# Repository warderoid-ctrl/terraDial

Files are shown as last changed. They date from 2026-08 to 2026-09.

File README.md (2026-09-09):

# terraDial

Standalone control panel for the **terraPen** pen plotter, running on an
Elecrow CrowPanel 1.28" round display — a 240×240 touchscreen with a rotary
knob. It talks to [FluidNC](http://wiki.fluidnc.com/) over a WebSocket, so
the plotter can be driven from the bench without a laptop or phone.

Parent project: [terraForge](https://github.com/theworkisthework/terraForge)
(the desktop app this panel descends from — and the source of its colour
palette). Sibling: terraPixel (the rail lighting controller this panel can
also drive).

## What it does

- **Jog** X/Y/Z by knob, with selectable step sizes (0.1 / 1 / 10 / 100mm on
  X and Y; Z is capped at 1mm, being only a pen lift) and a per-axis *Set zero*
- **Run G-code** straight off the plotter's SD card, with live progress,
  elapsed time and an estimate of the time remaining — including for jobs
  started from terraForge or the web UI rather than the panel
- **Pen up/down**, **homing** (with a clear-the-bed confirmation), **E-Stop**
  and **alarm clear**, the last showing FluidNC's own reason for the alarm
- **Park for photo** — one dial item that lifts the pen, homes, then runs the
  gantry out to the far end of Y so the finished plot can be photographed
  unobstructed. Sequenced against the status stream rather than fired blind,
  since G-code sent mid-homing is rejected
- **Rail lighting** control via terraPixel — brightness, film mode, comet width
- **On-device Wi-Fi setup**: scan for networks, pick one, type the password
- **Machine status** shown on the panel's 5-LED ring, readable across the room
  — a jog chases a pixel the way you turned the knob, a plot breathes the
  whole ring slowly, and both dim with the screen when the panel sleeps
- **Sleep mode** so the panel isn't glowing at you through a multi-hour plot,
  with the terraPen mark shown while idle beforehand
- **About screen** carrying the project identity and QR links to the site,
  source and Discord — a 240px dial is no place to read a URL

## Screens

> These are **vector illustrations, not photographs.** They're generated by
> [`tools/gen_screens.py`](tools/gen_screens.py) from the real layout values —
> palette hex, ring radii, arc angles, hub and font sizes — so proportions and
> colours match the firmware, but icons are simplified stand-ins for LVGL's
> symbol font and the panel's actual anti-aliasing isn't reproduced.

| | | |
|:--:|:--:|:--:|
| <br>**Home** — 8 destinations, E‑Stop always red | <br>**Jobs** — SD files on an open arc | <br>**Jog** — axis, position, per‑axis zero |
| <br>**Job progress** — elapsed, and time left | <br>**Pen** — up / down | <br>**Home XY** — clear‑the‑bed gate |
| <br>**Lights** — terraPixel rail control | <br>**Settings** — four categories | <br>**Display** — brightness, sleep |
| <br>**Radial keyboard** — knob‑first text entry | <br>**E‑Stop** — feed hold + soft reset | <br>**Alarm clear** — appears on alarm |
| <br>**About** — identity, QR links, diagnostics | <br>**Idle** — the mark, before sleep | |

## Hardware

| | |
|---|---|
| Board | Elecrow CrowPanel 1.28" Rotary (ESP32-S3R8, 16MB flash, 8MB PSRAM) |
| Display | GC9A01 240×240 round IPS, SPI |
| Touch | CST816D capacitive, I²C |
| Input | EC11-style rotary encoder with push switch |
| LEDs | 5× WS2812 ring around the bezel |

Pin assignments are in [`include/pins.h`](include/pins.h), confirmed against
Elecrow's factory example for this exact board rather than guessed.

### Power

It's a **USB-powered device** — a single USB-C lead carries both power and,
when you want it, the serial console and firmware flashing. There's no barrel
jack and no separate supply to find.

That also means it runs happily off a **USB battery pack**, which is handy for
a plotter that isn't parked next to a socket, or for filming without a cable
in shot. Two things worth knowing if you do:

- Many power banks cut out when they stop seeing meaningful current draw.
  This panel is a modest load to begin with, and screen sleep drops it further
  by switching the backlight off entirely — so a bank with an aggressive
  auto-shutoff may power down mid-plot. Banks with a "low-current" or
  "trickle" mode avoid this; otherwise turn sleep off (Settings → Display)
  when running from one.
- The bezel LED ring draws on the same supply, so a high ring brightness
  costs battery life directly. It's on the Lights screen if you want it down.

Enclosure files (`dial case.stl`, `frame mount.stl`, `backplate.dxf`) are in
the repo root.

## Installing and updating

Neither of these needs a toolchain, a checkout, or anything installed on the
computer. The Building section below is for changing the firmware, not for
running it.

### First install — the web installer

<https://warderoid-ctrl.github.io/terraDial/>

Plug the panel into a computer with a USB-C **data** cable, open that page in
Chrome or Edge on the desktop, and click *Connect and install*. It talks to the
panel over Web Serial and writes the whole chip — bootloader, partition table
and app — so it also works on a board that has never been flashed, and on one
that has been flashed with something broken.

Safari, Firefox and every mobile browser lack Web Serial, so the page tells
them so rather than failing halfway.

Released builds ship with **no Wi-Fi credentials baked in** — the first boot
comes up unconnected, and you pick a network on the panel (Settings → Wi-Fi →
scan). That's the flow a stranger's board has to use anyway, so it's the one
that gets tested.

### After that — over Wi-Fi, from the panel

**Settings → About → Check for updates.**

The panel asks GitHub for the latest release, compares it against the version
it's running, and offers to install it. It downloads into the spare app slot
and reboots into it, so a failed or interrupted download leaves the working
firmware exactly where it was — there's no window where the panel is holding
half a firmware.

Two deliberate limits:

- **It refuses while the machine is busy.** The download blocks the same task
  that pumps FluidNC's WebSocket, for a minute or more, and the reboot at the
  end drops the connection outright. Mid-plot is the worst possible moment for
  both, so it says "Machine busy" and does nothing.
- **A dev build is always offered the release.** A build from a working copy
  carries the version `dev`, which has no place in the ordering — see
  `include/version.h`. If you're testing local firmware, don't press the button.

The About card shows the running version at the top, which is the thing worth
quoting in a bug report.

### Cutting a release

Tag it and push the tag; [`.github/workflows/release.yml`](.github/workflows/release.yml)
does the rest.

```bash
git tag v0.1.0
git push origin v0.1.0
```

That builds the firmware with the tag stamped in, attaches two images to the
GitHub Release, and redeploys the installer page:

| Asset | What it is |
|---|---|
| `terradial-ota.bin` | The app image. What the panel downloads for itself — the name is fixed, and `OTA_ASSET_NAME` in [`src/net/ota_updater.h`](src/net/ota_updater.h) has to keep matching it |
| `terradial-factory.bin` | Bootloader + partitions + app, merged for flashing at `0x0`. What the web installer writes |

Publishing the installer page is a second workflow,
[`pages.yml`](.github/workflows/pages.yml), which the first triggers on
success. That split isn't tidiness: the `github-pages` environment only
accepts deployments from the default branch, and a release workflow runs from
a tag — v0.1.0 failed exactly that way. A `workflow_run` trigger is evaluated
in the default branch's context whatever ref set it off, so it passes the rule
without anyone having to loosen a protection setting that lives nowhere in the
repo.

It downloads the factory image from the release it just made and serves it
from the Pages origin rather than linking to github.com — Web Serial fetches
the image with JS, and a cross-origin fetch the browser declines fails
quietly, which is a miserable thing to debug from a report that only says
"the button doesn't work".

**One-time repo setup:** Settings → Pages → Source must be set to *GitHub
Actions*, or the workflow builds everything and has nowhere to publish it.

### Test builds nobody else gets

A tag with a hyphen in it — `v0.2.0-rc1` — publishes as a GitHub
*prerelease*. It gets a release page and downloadable binaries like any
other, but no panel is offered it and the installer page ignores it: both
ask for `releases/latest`, and that endpoint skips prereleases.

That's also the only safe way to use a suffix. `versionRank()` in the
updater stops at the first non-digit, so `0.2.0-rc1` ranks *identically* to
`0.2.0` — two different builds it cannot tell apart. Keeping suffixed tags
out of `latest` means it never has to.

### Versions can only go forwards

The updater offers a release only when it ranks strictly higher than the
running build, and there is no downgrade path in the UI. So a bad release is
retired by tagging a **higher** number — never by deleting the release,
moving the tag, or re-uploading under the same one. None of those reach a
panel that has already updated.

## Building

Built with [PlatformIO](https://platformio.org/).

```bash
# 1. Wi-Fi credentials and hostnames -- secrets.h is gitignored
cp include/secrets.h.example include/secrets.h
$EDITOR include/secrets.h

# 2. Build and flash
pio run -t upload

# 3. Watch the logs
pio device monitor
```

Only the SSID and password are compile-time *defaults*: they're seeded into
NVS on first boot, after which the Settings screen can change networks
on-device without a reflash.

A local build reports its version as `dev` unless HEAD is exactly on a tag —
[`tools/version.py`](tools/version.py) only treats an exact tag as a release,
because a commit that merely descends from `v0.2.0` is newer than `v0.2.0`, and
stamping it as that version would have the updater cheerfully offer to
downgrade it.

## Using it

The knob is the primary input; touch works everywhere too.

| Gesture | Does |
|---|---|
| Rotate | Move through a ring / jog the selected axis / scroll a settings panel |
| Click | Open the highlighted item, or confirm |
| Long press | Back (out of a category first, then out of the screen) |
| Tap the centre hub | The running job, the active alarm, or E-Stop if the machine is moving — otherwise whatever the hub is naming |
| Double click | Run/delete prompt (Jobs screen only) |

**Home** is a radial dial of eight destinations, ordered the way a session
actually runs rather than by category — Home XY, Jog, Pen, Jobs, Photo,
E-Stop, Lights, Settings. The ring rests on the first of them, so the first
thing under the selection when the panel wakes is the first thing you do.
**Jobs** and **Settings** use the same ring on an open arc, which keeps the
bottom of the face clear of the back button.

Job Progress and Alarm Clear appear on their own when a job starts or an
alarm trips, and have no dial item of their own. The way back to them is the
hub: it already reports the machine state, so while that state has a screen,
tapping it opens that screen rather than the selected ring item.

That's what buys the spacing. The ring is a full circle, so every item costs
the others angle — eight sit 45° apart where ten sat 36°. E-Stop is a chip
you have to land on while something is going wrong, so it gets the room; it
also stays red at every position rather than only when selected.

Getting to E-Stop matters most where the machine is already moving under
your hand, which is not during a job — Job Progress carries its own stop
button. It's **jogging** and **homing**. So the Jog and Park screens carry a
small red stop pip beside their back button, and on the dial, tapping the
hub while the machine is homing or travelling opens E-Stop. Both open the
E-Stop screen rather than stopping outright: a stray tap near the bottom
bezel shouldn't soft-reset a machine mid-plot.

E-Stop fires on **press**, not on release, and says what it did. An
emergency jab that lands and slides off is exactly the gesture a normal
button is designed to discard, and the panel can't tell you the machine
stopped — only whether there was a connection to send the stop down. So it
answers "STOPPED" or "NOT SENT", the second meaning go and stop it by hand.

## Layout

```
.github/         release build, and the installer-page deploy that follows it
docs/screens/    README illustrations (generated)
include/         pins, palette, LVGL config, shared enums
lib/CST816D/     vendor touch driver
src/
  config/        NVS-backed settings
  display/       all UI screens and shared widgets
  input/         encoder driver
  led/           WS2812 status ring
  net/           FluidNC WebSocket client, terraPixel HTTP client, Wi-Fi
tools/           icon, logo and screen-illustration generation
web/             the browser-based firmware installer (published to Pages)
design_handoff_radial_dial_ui/   the original design brief (historical)
```

Some notes worth knowing before changing things:

- **Networking runs on core 0**, in its own task (see `networkTask` in
  `main.cpp`). mDNS lookups, WebSocket reads and HTTP calls all block for
  seconds at a time; running them in `loop()` stalls rendering and touch.
  Commands travel UI→network through a queue, and **nothing outside that task
  may touch LVGL** — LVGL is single-threaded and lives on core 1.
- **It's a round screen.** Anything more than ~120px from centre (120,120) is
  behind the bezel and physically unreachable, corners included. Several bugs
  have come from laying out against the 240×240 square instead of the circle.
- **Avoid `transform_zoom` / `lv_img_set_zoom` on anything whose parent has
  opacity < 255.** That combination pushes LVGL down an offscreen-layer path
  that is unreliable on this board — it has twice caused elements to render
  blank or vanish. Change real sizes instead.
- Colours come from [`include/palette.h`](include/palette.h), ported from
  terraForge's dark theme. Use the tokens, not literal hex.
- **The dial's order lives in three places** and they must agree:
  `DIAL_ITEMS` in `ui_dial.cpp`, the positional `switch` in `ui_nav.cpp`'s
  `onDialOpen()`, and the `screen_home()` item list in `tools/gen_screens.py`.
  Reordering one alone doesn't fail to build — it just quietly sends every
  item to the wrong screen.
- **Pace what you send FluidNC.** Commands are queued and the whole queue is
  drained in one pass, so two lines enqueued together hit the wire
  microseconds apart. `$X` immediately followed by `$H` used to alarm the
  machine on any home after the first; `home()` now unlocks only when there's
  actually an alarm and holds the `$H` until that has landed. For the same
  reason jogging is refused mid-homing — the jog-cancel realtime byte would
  stop the cycle, and FluidNC alarms on a homing cycle that didn't finish.
- Project links live in [`include/branding.h`](include/branding.h). The
  Discord URL is deliberately empty until there's a real invite — an entry
  with no URL is skipped rather than rendered as a QR that goes nowhere.
  `githubOwner()`/`githubRepo()` there are also what the updater queries, so
  a repo rename means editing them. The old **terraTouch** name still
  resolves, but only as a 301, and GitHub's API answers a redirect with a
  note about the move rather than the release — which is why the updater
  follows redirects, so a rename can't quietly kill the update path on
  panels already in the field.
- **`default_16MB.csv` is load-bearing.** The two app slots are what the OTA
  updater flashes into. A single-app partition table builds and runs perfectly
  and then fails every update at the point of no return.

## Licence

MIT — see [LICENSE](LICENSE). Same licence as its parent project
[terraForge](https://github.com/theworkisthework/terraForge).

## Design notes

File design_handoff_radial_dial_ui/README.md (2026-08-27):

# Handoff: TerraPen Dial Controller UI (historical)

> **Status: superseded. The firmware is the source of truth, not this file.**
>
> This is the design brief the panel was originally built from, kept for
> provenance — it's why the UI looks the way it does, and the palette,
> typography and icon-set sections below are still accurate and still worth
> reading before adding a screen.
>
> Everything describing *behaviour* has been overtaken by the shipped
> firmware. Where the two disagree, the firmware wins. The known divergences,
> as of the rename to terraDial:
>
> - **Home is a ring of nine, not eight**, and in a different order: Home XY,
>   Jog, Pen, Jobs, Progress, E-Stop, Alarm, Lights, Settings. `DIAL_ITEMS` in
>   `src/display/ui_dial.cpp` is authoritative.
> - **Job Progress is a dial destination**, not only an automatic screen.
> - **Jobs and Settings are rings on an open arc**, not carousels.
> - **There is no separate physical touch button** on this hardware. Back is a
>   knob long-press; E-Stop is a dial item, not a double-press gesture.
> - **Homing does not unconditionally send `$X`.** It unlocks only when the
>   machine is actually alarmed, and holds the `$H` until that has landed —
>   sending both together alarms the machine on any home after the first. See
>   the README's note on pacing FluidNC commands.
> - **The job-progress screen has no "pen down" pill.** It was redundant and
>   collided with the back button. It gained elapsed time and an estimate of
>   time remaining instead.
> - **Text entry exists**: the radial keyboard, which this brief lists as not
>   yet designed.

## Overview
Screen mockups for the terraPen/terraForge companion controller: a round CrowPanel 1.28" ESP32 HMI display (240×240 IPS, capacitive touch + a rotary knob that also clicks, plus a separate physical touch button). Home is a radial dial (8 destinations arranged around the ring, spring-eased rotation on select). Jobs and Settings use a carousel pattern since those lists don't fit a ring as cleanly.

Grounded against the real `terraDial` repo (warderoid-ctrl/terraDial, then named terraTouch) — palette hex values, the 8 Home destinations and their order, and the Lights/Settings screen contents all match `include/palette.h`, `src/display/ui_dial.cpp`, `ui_lights.cpp`, and `ui_settings.cpp`. (At the time of writing, `ui_dial.cpp` still implemented Home as a carousel and this brief was asking for the radial dial that has since shipped.)

## About the Design Files
The bundled file (`TerraPen Dial UI.dc.html`) is a **design reference built in HTML/CSS**, viewable in any browser. It is NOT code to embed — the target runtime is almost certainly **LVGL on ESP32/TFT_eSPI** (per the `terrapen-LCD-UI` repo), so recreate these layouts using LVGL widgets (`lv_arc`, `lv_img`/`lv_canvas` for icons, `lv_label`, etc.) at the real **240×240px** resolution. If a different target stack is used instead, adapt to its existing environment/patterns rather than porting the HTML directly.

## Fidelity
High-fidelity for color, layout proportion, and icon choice. Pixel positions are given at the 440×440 mockup scale — divide by ~1.83 to map to the real 240×240 screen (or better: treat the proportions/percentages as source of truth, not literal px).

All screens were grounded in the repo as it stood when this was written; several have moved on since.

## Screens
1. **Home** — radial dial of 8 destinations: Jobs, Jog, Pen, Lights, Home (clear+$X), E-Stop, Alarm, Settings (order matches `ui_dial.cpp`'s `DIAL_ITEMS`). All 8 sit on a ring at a fixed radius from center; the one nearest the top slot is largest/brightest (accent fill), others shrink and fade continuously with angular distance from top. Rotating the knob spins the ring with a springy eased transition (~550ms, overshoot easing) instead of the old flat carousel swap; knob click or tap opens the item nearest the top.
2. **Jobs (SD card)** — carousel of files on the SD card. Center card shows file icon, filename truncated to one line with ellipsis (never wraps) + a second small line for the remainder, meta (point count, est. time), and a "Run job" pill. Long filenames are the normal case, not an edge case — design accordingly.
3. **Job in progress (Plotting)** — progress ring drawn by layering: outer conic-gradient ring (12px inset) + inner circle matching background (23px inset) leaves an ~11px arc band. Center: percentage (52px bold) + time remaining. Pause/stop 58px circular buttons below. "pen down" status pill near the bottom edge.
4. **Jog** — X/Y/Z axis chips at top (Y active in the mock). Big position readout center, ± 58px circular jog buttons either side. Increment chip row: 0.1 / 1 / 10 mm — **Z axis omits the 10mm chip**, only 0.1/1 available; called out in an on-screen caption.
5. **Pen up/down** — a segmented control (not a toggle switch), "Pen up" / "Pen down", accent fill on the active side. Tap either half or click the knob to flip.
6. **Lights** — brightness sliders for "Dial ring" and "terraPen LED" plus 4 colour-preset swatches for the dial ring (matches `ui_lights.cpp`).
7. **Home / clear prompt** — safety gate shown before homing: icon + "Clear the bed first" + body copy + "Confirm & home" pill. Confirming sends `$X` (unlock) then homes.
8. **E-Stop** — single always-reachable action. Big red circular button (a muted safety-red, `oklch(62% 0.19 25)`, to avoid a jarring pure red against the rest of the palette) with alert icon, "E-STOP" label, "Feed hold + soft reset" subtext. Should also be triggerable by double-pressing the physical touch button from any screen.
9. **Alarm clear** — shows the alarm reason (e.g. "Hard limit triggered · Z−"), not just a bare button. "Clear alarm" pill sends `$X`. Intended to appear automatically when an alarm trips.
10. **Settings** — carousel: Wi-Fi (SSID, password dots, Connect pill — shown as the main card), Machine, Display, About (matches `ui_settings.cpp`). On-screen keyboard for SSID/password entry not designed yet.

## Interactions & Behavior
- **Rotary knob rotation**: pages the active carousel (Home/Jobs/Settings), jogs the active axis (Jog), or adjusts the focused slider (Lights).
- **Rotary knob click**: confirms/opens the highlighted card; flips Pen up/down; confirms Home/Alarm-clear prompts.
- **Touchscreen tap**: direct-select any card/button/chip.
- **Physical touch button**: back/home from any screen; double-press = E-Stop from anywhere.
- No transition/animation timing was specified — recommend a quick (150–200ms) ease for card paging and state changes.
- Firmware commands referenced: `$X` (alarm unlock, used by both the Home-clear flow and Alarm-clear), homing after unlock on the Home flow. **Superseded** — see the divergence note at the top: unlocking unconditionally before `$H` is what made repeat homing alarm.

## Design Tokens
Mockup OKLCH values below match the real hex values already committed to `include/palette.h` — that file is the source of truth for firmware; these are the equivalent OKLCH mixes used to build this mockup in HTML.
- **Background (page canvas, not device)**: `oklch(96% 0.006 80)` warm off-white
- **Screen background**: radial-gradient `oklch(29% 0.025 290)` → `oklch(15% 0.02 290)` (deep graphite-lavender) — `Palette::bgApp() 0x201e29` / hub `Palette::bgTerminal() 0x322f3e`
- **Foreground/primary text**: `oklch(97% 0.005 90)`
- **Muted text/icons/border**: `oklch(60–70% 0.02 290)` — `Palette::border() 0x71707d`, `Palette::textMuted() 0x8f8d9b`
- **Accent (primary, selection/progress)**: `oklch(78% 0.09 300)` — lavender — `Palette::accent() 0xc0abe9`
- **Accent (secondary, network/pen-down/alarm)**: `oklch(80% 0.08 45)` — warm peach — `Palette::accentSecondary() 0xeaae93`
- **Accent foreground (text/icons on accent fills)**: `Palette::accentFg() 0x18141f`
- **Selected-row fill**: `Palette::selectedFill() 0x453a5e`
- **Alert (E-Stop only)**: `oklch(62% 0.19 25)` — muted safety red — `Palette::alert() 0xc4483f`
- **Typography**: Manrope (400/500/600/700/800) for UI text; JetBrains Mono (500/600) for small-caps labels/eyebrow text
- Icon set: **Lucide** (thin 2px stroke, rounded caps/joins) — icons used: layers, target, file, sliders-horizontal, activity, plus, play, clock, layout-grid, pause, square, wifi, sun, cpu, info, maximize (jog), pen-line, lightbulb, home, unlock, alert-circle

## Assets
No external image assets — all icons are inline Lucide SVGs; the file thumbnail is a placeholder striped pattern (real plot-preview thumbnails to be substituted).

## Files
- `TerraPen Dial UI.dc.html` — the full mockup set (open in a browser; view source for exact markup/CSS values).

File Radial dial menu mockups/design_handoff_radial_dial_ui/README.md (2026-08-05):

# Handoff: TerraPen Dial Controller UI

## Overview
Screen mockups for the terraPen/terraForge companion controller: a round CrowPanel 1.28" ESP32 HMI display (240×240 IPS, capacitive touch + a rotary knob that also clicks, plus a separate physical touch button). All multi-item menus use a carousel pattern (not a radial ring) since Home alone has 8 destinations.

## About the Design Files
The bundled file (`TerraPen Dial UI.dc.html`) is a **design reference built in HTML/CSS**, viewable in any browser. It is NOT code to embed — the target runtime is almost certainly **LVGL on ESP32/TFT_eSPI** (per the `terrapen-LCD-UI` repo), so recreate these layouts using LVGL widgets (`lv_arc`, `lv_img`/`lv_canvas` for icons, `lv_label`, etc.) at the real **240×240px** resolution. If a different target stack is used instead, adapt to its existing environment/patterns rather than porting the HTML directly.

## Fidelity
High-fidelity for color, layout proportion, and icon choice. Pixel positions are given at the 440×440 mockup scale — divide by ~1.83 to map to the real 240×240 screen (or better: treat the proportions/percentages as source of truth, not literal px).

**Open gap:** the "Lights" screen and the extra Settings items (beyond Wi-Fi) are inferred, not sourced — the `terraTouch` repo referenced in chat was never actually shared into this project. Get that link and correct those two screens before building.

## Screens
1. **Home** — carousel of 8 destinations: Jobs, Jog, Pen, Lights, Home (clear+$X), E-Stop, Alarm Clear, Settings. Center card 190×190 (icon + label), dimmed neighbor cards peek at the edges, "n of 8" index text below. Knob rotation pages, knob click or tap opens.
2. **Jobs (SD card)** — carousel of files on the SD card. Center card shows file icon, filename truncated to one line with ellipsis (never wraps) + a second small line for the remainder, meta (point count, est. time), and a "Run job" pill. Long filenames are the normal case, not an edge case — design accordingly.
3. **Job in progress (Plotting)** — progress ring drawn by layering: outer conic-gradient ring (12px inset) + inner circle matching background (23px inset) leaves an ~11px arc band. Center: percentage (52px bold) + time remaining. Pause/stop 58px circular buttons below. "pen down" status pill near the bottom edge.
4. **Jog** — X/Y/Z axis chips at top (Y active in the mock). Big position readout center, ± 58px circular jog buttons either side. Increment chip row: 0.1 / 1 / 10 mm — **Z axis omits the 10mm chip**, only 0.1/1 available; called out in an on-screen caption.
5. **Pen up/down** — a segmented control (not a toggle switch), "Pen up" / "Pen down", accent fill on the active side. Tap either half or click the knob to flip.
6. **Lights** *(inferred — see gap above)* — brightness sliders for "Dial ring" and "terraPen LED" plus 4 colour-preset swatches for the dial ring.
7. **Home / clear prompt** — safety gate shown before homing: icon + "Clear the bed first" + body copy + "Confirm & home" pill. Confirming sends `$X` (unlock) then homes.
8. **E-Stop** — single always-reachable action. Big red circular button (a muted safety-red, `oklch(62% 0.19 25)`, to avoid a jarring pure red against the rest of the palette) with alert icon, "E-STOP" label, "Feed hold + soft reset" subtext. Should also be triggerable by double-pressing the physical touch button from any screen.
9. **Alarm clear** — shows the alarm reason (e.g. "Hard limit triggered · Z−"), not just a bare button. "Clear alarm" pill sends `$X`. Intended to appear automatically when an alarm trips.
10. **Settings** — carousel: Wi-Fi (SSID, password dots, Connect pill — shown as the main card), Machine, Display, About *(items 2–4 inferred — see gap above)*. On-screen keyboard for SSID/password entry not designed yet.

## Interactions & Behavior
- **Rotary knob rotation**: pages the active carousel (Home/Jobs/Settings), jogs the active axis (Jog), or adjusts the focused slider (Lights).
- **Rotary knob click**: confirms/opens the highlighted card; flips Pen up/down; confirms Home/Alarm-clear prompts.
- **Touchscreen tap**: direct-select any card/button/chip.
- **Physical touch button**: back/home from any screen; double-press = E-Stop from anywhere.
- No transition/animation timing was specified — recommend a quick (150–200ms) ease for card paging and state changes.
- Firmware commands referenced: `$X` (alarm unlock, used by both the Home-clear flow and Alarm-clear), homing after unlock on the Home flow.

## Design Tokens
- **Background (page canvas, not device)**: `oklch(96% 0.006 80)` warm off-white
- **Screen background**: radial-gradient `oklch(29% 0.025 290)` → `oklch(15% 0.02 290)` (deep graphite-lavender)
- **Foreground/primary text**: `oklch(97% 0.005 90)`
- **Muted text/icons**: `oklch(60–70% 0.02 290)`
- **Accent (primary, selection/progress)**: `oklch(78% 0.09 300)` — lavender
- **Accent (secondary, network/pen-down/alarm)**: `oklch(80% 0.08 45)` — warm peach
- **Alert (E-Stop only)**: `oklch(62% 0.19 25)` — muted safety red
- **Typography**: Manrope (400/500/600/700/800) for UI text; JetBrains Mono (500/600) for small-caps labels/eyebrow text
- Icon set: **Lucide** (thin 2px stroke, rounded caps/joins) — icons used: layers, target, file, sliders-horizontal, activity, plus, play, clock, layout-grid, pause, square, wifi, sun, cpu, info, maximize (jog), pen-line, lightbulb, home, unlock, alert-circle

## Assets
No external image assets — all icons are inline Lucide SVGs; the file thumbnail is a placeholder striped pattern (real plot-preview thumbnails to be substituted).

## Files
- `TerraPen Dial UI.dc.html` — the full mockup set (open in a browser; view source for exact markup/CSS values).

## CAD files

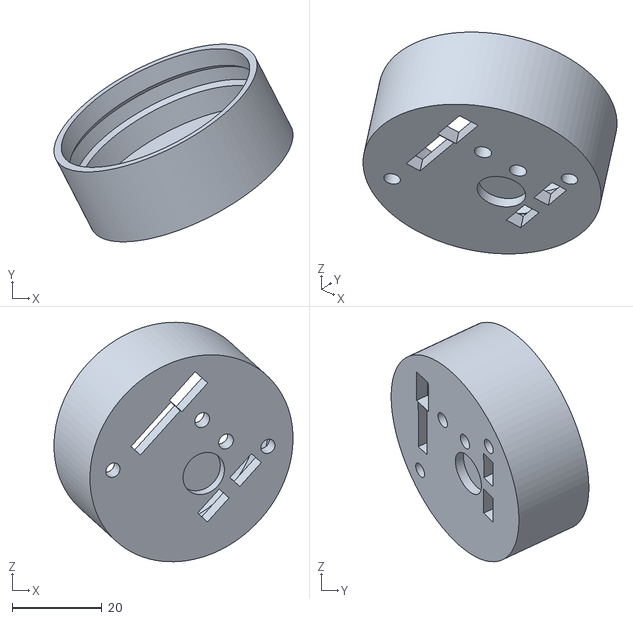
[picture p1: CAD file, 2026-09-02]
dial case.stl
53.3 x 44.1 x 53.5

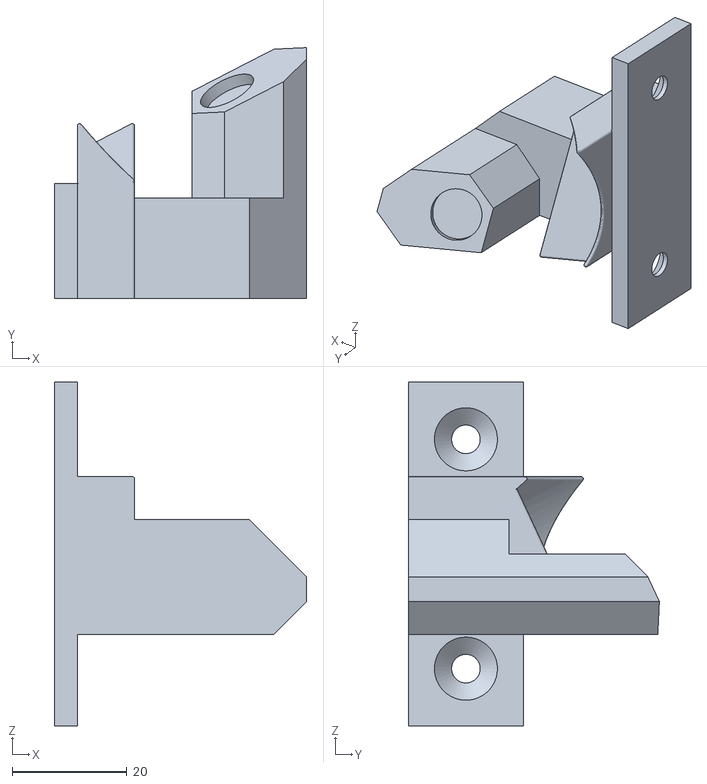
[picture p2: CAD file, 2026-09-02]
frame mount.stl
44.0 x 43.7 x 60.0

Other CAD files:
backplate.dxf

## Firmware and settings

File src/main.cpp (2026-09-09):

#include <Arduino.h>
#include <lvgl.h>
#include "pins.h"
#include "version.h"
#include "config/settings.h"
#include "display/lgfx_config.h"
#include "display/ui_nav.h"
#include "display/ui_dial.h"
#include "display/ui_jog.h"
#include "display/ui_files.h"
#include "display/ui_lights.h"
#include "display/ui_settings.h"
#include "display/ui_job_progress.h"
#include "display/ui_park.h"
#include "display/screen_sleep.h"
#include "input/encoder.h"
#include "led/panel_ring.h"
#include "net/fluidnc_client.h"
#include "net/terrapixel_client.h"
#include "net/wifi_manager.h"
#include "net/ota_updater.h"
#include <CST816D.h>

// ---- terraDial: CrowPanel round-screen control panel for terraPen ----
// See the project plan for the staged build order; this file wires
// together display/touch/encoder/LEDs, the FluidNC + terraPixel clients,
// and the backlight idle timeout.

static LGFX gfx;
static CST816D touch(PIN_TOUCH_SDA, PIN_TOUCH_SCL, PIN_TOUCH_RST, PIN_TOUCH_INT);

static const uint32_t SCREEN_W = 240;
static const uint32_t SCREEN_H = 240;

// "Full" is whatever the user set on the Settings > Display brightness
// slider, not a fixed 100.
static uint8_t backlightFullPct() { return Config::get().backlightBrightnessPct; }
static const uint32_t STATUS_UI_REFRESH_MS = 150; // back to the original value -- chasing lower latency here was adding background redraw/network load the ESP32 didn't have to spare

static lv_disp_draw_buf_t drawBuf;
static lv_color_t *lvBuf0 = nullptr;
static lv_color_t *lvBuf1 = nullptr;

static void dispFlush(lv_disp_drv_t *disp, const lv_area_t *area, lv_color_t *colorP)
{
    // pushImageDMA() returns as soon as the transfer is QUEUED, not when the
    // pixels have landed. The previous version signalled lv_disp_flush_ready()
    // straight afterwards, so LVGL was free to start rendering the next frame
    // into a buffer the DMA engine was still reading -- which is exactly what
    // fast scrolling looked like: torn, half-updated frames.
    //
    // startWrite/endWrite brackets the transfer and endWrite() waits for DMA
    // to drain, so the buffer is genuinely free by the time we report done.
    uint32_t w = area->x2 - area->x1 + 1;
    uint32_t h = area->y2 - area->y1 + 1;
    gfx.startWrite();
    gfx.setAddrWindow(area->x1, area->y1, w, h);
    gfx.writePixels((lgfx::rgb565_t *)&colorP->full, w * h);
    gfx.endWrite();
    lv_disp_flush_ready(disp);
}

// The CST816D driver reports raw touch coordinates in the panel's native
// (unrotated) frame -- we read it directly rather than through LGFX's own
// touch abstraction, so WE have to apply the same rotation as
// gfx.setRotation(DISPLAY_ROTATION) or taps land in the wrong place versus
// what's visually displayed.
static void rotateTouchCoords(uint16_t &x, uint16_t &y)
{
#if DISPLAY_ROTATION == 1
    uint16_t nx = SCREEN_H - 1 - y;
    uint16_t ny = x;
    x = nx;
    y = ny;
#elif DISPLAY_ROTATION == 2
    x = SCREEN_W - 1 - x;
    y = SCREEN_H - 1 - y;
#elif DISPLAY_ROTATION == 3
    // Confirmed on hardware: the straightforward 90deg transform here
    // landed taps exactly 180deg opposite the wedge that was actually
    // tapped (e.g. tapping "Stop" opened "Pen", exactly across the dial) --
    // this is that transform with the 180deg error already cancelled out,
    // not a generic "rotation 3" formula.
    uint16_t nx = SCREEN_W - 1 - y;
    uint16_t ny = x;
    x = nx;
    y = ny;
#endif
    // DISPLAY_ROTATION == 0: no transform needed.
}

static void touchpadRead(lv_indev_drv_t *drv, lv_indev_data_t *data)
{
    // Held for the whole duration of a press that merely woke the panel, so
    // LVGL never sees it. Without the latch only the first read would be
    // swallowed and the rest of the same press would land on whatever
    // happened to be under the finger.
    static bool swallowUntilRelease = false;

    uint16_t x, y;
    uint8_t gesture;
    bool touched = touch.getTouch(&x, &y, &gesture);
    if (!touched)
    {
        swallowUntilRelease = false;
        data->state = LV_INDEV_STATE_REL;
        return;
    }

    if (ScreenSleep::noteInputAndWake()) swallowUntilRelease = true;
    if (swallowUntilRelease)
    {
        data->state = LV_INDEV_STATE_REL;
        return;
    }

    rotateTouchCoords(x, y);
    data->state = LV_INDEV_STATE_PR;
    data->point.x = x;
    data->point.y = y;
}

// Must happen before touch/display init: this panel gates its
// display/backlight power rail behind these two GPIOs (see pins.h).
// Without this, the backlight never lights regardless of the PWM
// value written to PIN_LCD_BACKLIGHT.
static void initPowerRails()
{
    pinMode(PIN_POWER_RAIL_1, OUTPUT);
    digitalWrite(PIN_POWER_RAIL_1, HIGH);
    pinMode(PIN_POWER_RAIL_2, OUTPUT);
    digitalWrite(PIN_POWER_RAIL_2, HIGH);

    pinMode(PIN_POWER_LED, OUTPUT);
    digitalWrite(PIN_POWER_LED, LOW);
}

static void initTouchAndDisplay()
{
    touch.begin();
    Serial.println("touch.begin() done");

    gfx.init();
    gfx.setRotation(DISPLAY_ROTATION);
    gfx.initDMA();
    gfx.startWrite();
    gfx.fillScreen(TFT_BLACK);
    // Balance the startWrite above. It used to be left dangling, which the
    // old dispFlush() compensated for by calling endWrite() on entry -- with
    // dispFlush now bracketing its own transfers, an unmatched count here
    // would leave every frame's endWrite() one level short of actually
    // waiting for DMA.
    gfx.endWrite();

    lv_init();

    size_t bufSize = sizeof(lv_color_t) * SCREEN_W * SCREEN_H;
    lvBuf0 = (lv_color_t *)heap_caps_malloc(bufSize, MALLOC_CAP_SPIRAM);
    lvBuf1 = (lv_color_t *)heap_caps_malloc(bufSize, MALLOC_CAP_SPIRAM);
    if (!lvBuf0 || !lvBuf1)
    {
        Serial.println("Failed to allocate LVGL draw buffers from PSRAM!");
    }
    lv_disp_draw_buf_init(&drawBuf, lvBuf0, lvBuf1, SCREEN_W * SCREEN_H);

    static lv_disp_drv_t dispDrv;
    lv_disp_drv_init(&dispDrv);
    dispDrv.hor_res = SCREEN_W;
    dispDrv.ver_res = SCREEN_H;
    dispDrv.flush_cb = dispFlush;
    dispDrv.draw_buf = &drawBuf;
    lv_disp_drv_register(&dispDrv);

    static lv_indev_drv_t indevDrv;
    lv_indev_drv_init(&indevDrv);
    indevDrv.type = LV_INDEV_TYPE_POINTER;
    indevDrv.read_cb = touchpadRead;
    lv_indev_drv_register(&indevDrv);
}

// Everything network-related runs here, on core 0, NOT in loop().
//
// This is the fix for the panel stuttering whenever the plotter was
// connected. All three network paths block for a long time by design:
// MDNS.queryHost() waits up to 1.5-2s, WebSocketsClient's frame reader
// spins until a partially-arrived frame completes, and TerraPixelClient's
// HTTP calls wait up to 1s. Running any of those in loop() stalls
// lv_timer_handler() and the touch driver for exactly that long -- which is
// why input felt fine at boot and then "laggy, then catches up" once
// FluidNC (or an absent terraPixel) was in the picture.
//
// Arduino's loop() runs on core 1, so pinning this to core 0 means a
// blocked socket can no longer delay a redraw or a button press. Commands
// travel UI->network through FluidNCClient's queue; status travels back as
// plain struct reads. Nothing here touches LVGL -- LVGL is single-threaded
// and stays entirely on core 1.
static void networkTask(void *)
{
    for (;;)
    {
        WifiManager::update();
        if (WifiManager::isReady())
        {
            fluidNC.update();
            // terraPixel's HTTP calls block this task for up to a second
            // each (longer if its mDNS name doesn't resolve), and nothing
            // pumps the FluidNC websocket or drains the command queue while
            // they do. Harmless when the machine is parked; during a homing
            // cycle or a job it means seconds-long gaps on a channel
            // FluidNC is actively talking on. So the lights wait until the
            // machine has stopped moving -- they refresh every 3s anyway,
            // and a few skipped polls cost nothing.
            MachineMode m = fluidNC.status().mode;
            if (m != MachineMode::Homing && m != MachineMode::Run && m != MachineMode::Hold)
                terraPixel.update(); // blocking HTTP -- belongs here, not on the UI loop

            // Same reasoning again, one step further: a firmware download
            // holds this task for the length of the transfer. It only runs
            // when the About card has actually asked for it, and it refuses
            // outright while the machine is moving (see ota_updater.cpp).
            OtaUpdater::update();
        }
        vTaskDelay(pdMS_TO_TICKS(2));
    }
}

static void startNetworkTask()
{
    xTaskCreatePinnedToCore(networkTask, "net", 8192, nullptr, 1, nullptr, 0);
}

void setup()
{
    Serial.begin(115200);
    delay(300); // give the USB-CDC serial monitor time to attach before the first prints
    Serial.printf("terraDial boot -- firmware %s\n", Version::firmware());

    Config::begin();

    initPowerRails();
    initTouchAndDisplay();
    jogWheel.begin();

    UiNav::begin();

    panelRing.begin();
    panelRing.setMode(MachineMode::Boot);

    backlightInit();
    ScreenSleep::begin();
    backlightSet(backlightFullPct()); // backlightInit() defaults to full -- honour the saved level

    fluidNC.initTransport(); // command queue must exist before the UI can enqueue
    WifiManager::begin();
    startNetworkTask();

    Serial.println("terraDial stage-2 bring-up ready");
}

void loop()
{
    lv_timer_handler();
    jogWheel.update();
    UiNav::update(); // also drives uiLightsUpdate(), but only while Lights is on screen

    // WifiManager::update()/fluidNC.update() deliberately absent -- they run
    // on networkTask (core 0) so their blocking calls can't stall the UI.

    uiFilesUpdate();
    uiSettingsUpdate();
    // Unconditional, not gated on the Park screen being visible: the macro
    // takes the length of a homing cycle, and the whole point is that you
    // can walk away to another screen while it runs.
    uiParkUpdate();

    panelRing.setMode(fluidNC.status().mode);
    // FluidNC calls a jog and a plot the same thing (Run); this is the half
    // of the distinction the ring can't work out for itself.
    panelRing.setPlotting(fluidNC.status().jobActive);
    panelRing.update();

    static uint32_t lastStatusUiUpdate = 0;
    if (millis() - lastStatusUiUpdate > STATUS_UI_REFRESH_MS)
    {
        lastStatusUiUpdate = millis();
        uiDialUpdate(fluidNC.status());
        uiJogUpdate(fluidNC.status());
        uiJobProgressUpdate(fluidNC.status());
    }

    ScreenSleep::update();

    // A finished OTA reboots from here rather than from inside
    // httpUpdate.update(): rebooting on the network task would cut the panel
    // dark mid-frame, with the last thing on screen being a progress bar at
    // 99%. The pause gives LVGL a couple of frames to paint "restarting" so
    // the user sees why the screen went away.
    static uint32_t otaRestartAt = 0;
    if (OtaUpdater::restartPending())
    {
        if (otaRestartAt == 0) otaRestartAt = millis() + 1200;
        else if ((int32_t)(millis() - otaRestartAt) >= 0)
        {
            Serial.println("[ota] restarting into the new firmware");
            Serial.flush();
            ESP.restart();
        }
    }

    // Restored to the original 5ms -- cutting it chasing lower input latency
    // left the WiFi/BT background task (and the I2C touch driver's own
    // timing) too little room on this core, which made things feel
    // laggier, not snappier.
    delay(5);
}

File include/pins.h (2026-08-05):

#pragma once

// Single source of truth for the CrowPanel 1.28" Rotary Display pin map.
// Confirmed against Elecrow's factory example firmware for this exact
// board (example/RotaryScreen_1_28_new), not guessed.

// ---- Display (GC9A01, SPI2_HOST) ----
#define PIN_LCD_SCLK 10
#define PIN_LCD_MOSI 11
#define PIN_LCD_MISO -1
#define PIN_LCD_DC 3
#define PIN_LCD_CS 9
#define PIN_LCD_RST 14
#define PIN_LCD_BACKLIGHT 46

// ---- Touch (CST816D, on Wire1) ----
#define PIN_TOUCH_SDA 6
#define PIN_TOUCH_SCL 7
#define PIN_TOUCH_INT 5
#define PIN_TOUCH_RST 13

// ---- Rotary encoder / jog wheel ----
#define PIN_ENCODER_A 45 // CLK
#define PIN_ENCODER_B 42 // DT
#define PIN_ENCODER_SW 41 // push button, active-low

// ---- Onboard LED ring (5x WS2812, GRB) ----
#define PIN_LED_RING 48
#define LED_RING_COUNT 5

// ---- Power indicator LED ----
#define PIN_POWER_LED 40

// ---- Power-enable rail ----
// Confirmed from Elecrow's factory example: these two GPIOs gate a power
// rail feeding the display/backlight circuitry and must be driven HIGH
// before anything else, or the backlight stays dark no matter what's
// written to PIN_LCD_BACKLIGHT -- the example's own comments just call
// them "power pin, output current" without saying what they feed.
#define PIN_POWER_RAIL_1 1
#define PIN_POWER_RAIL_2 2

// Backlight PWM channel config (ledc)
#define BACKLIGHT_PWM_CHANNEL 0
#define BACKLIGHT_PWM_FREQ 5000
#define BACKLIGHT_PWM_RESOLUTION 8

// ---- Physical mounting rotation ----
// LovyanGFX setRotation() step, 0-3 (each step = 90 deg). Set so the UI
// reads upright given how the panel is physically mounted (e.g. which side
// the cable exits). main.cpp's touchpadRead() applies a matching coordinate
// transform -- if you change this, touch has to rotate with it or taps
// land in the wrong place.
//
// 3 is a first guess at "90 deg counter-clockwise from the factory default"
// -- rotation direction conventions are easy to get backwards without the
// hardware in hand. If the display rotates the wrong way, or rotates right
// but touch is offset, try 1 instead (the other 90 deg step) and say what
// you saw.
#define DISPLAY_ROTATION 3

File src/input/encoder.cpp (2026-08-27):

#include "encoder.h"
#include <Arduino.h>
#include "pins.h"

JogWheel jogWheel;

namespace
{
    // Interrupt-driven quadrature decode, standard 2-bit state-transition
    // table: index = (prevState<<2)|newState, each state is (A<<1)|B.
    // Invalid/bounce transitions (both bits appearing to change at once)
    // map to 0 and are ignored rather than guessed at.
    volatile int8_t qLastState = 0;
    volatile int32_t qRawTicks = 0;

    const int8_t QUAD_TABLE[16] = {
        0, -1, 1, 0,
        1, 0, 0, -1,
        -1, 0, 0, 1,
        0, 1, -1, 0
    };

    void IRAM_ATTR onEncoderChange()
    {
        uint8_t a = digitalRead(PIN_ENCODER_A);
        uint8_t b = digitalRead(PIN_ENCODER_B);
        uint8_t newState = (a << 1) | b;
        uint8_t idx = ((uint8_t)qLastState << 2) | newState;
        qRawTicks += QUAD_TABLE[idx & 0x0F];
        qLastState = newState;
    }

    // This EC11-style mechanical encoder latches at one detent per full
    // 4-tick quadrature cycle (the common case for these panel jog wheels).
    const int32_t TICKS_PER_DETENT = 4;
}

void JogWheel::begin()
{
    pinMode(PIN_ENCODER_A, INPUT);
    pinMode(PIN_ENCODER_B, INPUT);
    pinMode(PIN_ENCODER_SW, INPUT_PULLUP);

    qLastState = (digitalRead(PIN_ENCODER_A) << 1) | digitalRead(PIN_ENCODER_B);
    attachInterrupt(digitalPinToInterrupt(PIN_ENCODER_A), onEncoderChange, CHANGE);
    attachInterrupt(digitalPinToInterrupt(PIN_ENCODER_B), onEncoderChange, CHANGE);
}

void JogWheel::update()
{
    updateRotation();
    updateButton();
}

void JogWheel::updateRotation()
{
    noInterrupts();
    int32_t ticks = qRawTicks;
    interrupts();

    int32_t diff = ticks - lastRawTicks_;
    lastRawTicks_ = ticks;

    // Throw away the sub-detent remainder when the direction reverses.
    //
    // This is what made the first turn back after a change of direction do
    // nothing (reported as needing "two or more turns" to reverse). A
    // detented wheel always comes to rest ON a latch, so a non-zero
    // pendingTicks_ isn't real travel that's owed to us -- it's accumulated
    // error, from the ISR reading both pins already changed on a fast spin
    // and scoring that transition 0 instead of 2. Carried forward, that
    // error is signed: a remainder of +2 left over from turning clockwise
    // has to be paid off before a counter-clockwise detent can register, so
    // the first turn back costs 6 ticks instead of 4 and looks ignored.
    // Worse, it never settles -- the leftover just flips sign and taxes the
    // NEXT reversal too.
    //
    // Same-direction turning is untouched: the remainder is only discarded
    // when its sign opposes the new movement.
    if ((diff > 0 && pendingTicks_ < 0) || (diff < 0 && pendingTicks_ > 0)) pendingTicks_ = 0;

    pendingTicks_ += diff;

    int32_t detents = pendingTicks_ / TICKS_PER_DETENT;
    pendingTicks_ -= detents * TICKS_PER_DETENT;
    rotationAccum_ += detents;

    if (detents != 0) lastActivityAt_ = millis();
}

void JogWheel::updateButton()
{
    uint32_t now = millis();
    bool rawLow = digitalRead(PIN_ENCODER_SW) == LOW;

    if (rawLow != rawLevelLow_)
    {
        rawLevelLow_ = rawLow;
        levelSince_ = now;
    }
    else if (now - levelSince_ >= DEBOUNCE_MS)
    {
        // Stable reading -- act on transitions into/out of "pressed".
        if (rawLow && !pressed_)
        {
            pressed_ = true;
            pressedAt_ = now;
            longPressFired_ = false;
            suppressPress_ = false;
            pressStartRawTicks_ = lastRawTicks_;
            lastActivityAt_ = now;
        }
        else if (!rawLow && pressed_)
        {
            pressed_ = false;
            if (!longPressFired_ && !suppressPress_)
            {
                pendingClicks_++;
                lastReleaseAt_ = now;
            }
        }
    }

    int32_t movedTicks = lastRawTicks_ - pressStartRawTicks_;
    if (movedTicks < 0) movedTicks = -movedTicks;
    if (pressed_ && !suppressPress_ && movedTicks > PRESS_MOVEMENT_SUPPRESS_TICKS)
    {
        suppressPress_ = true;
    }

    if (pressed_ && !suppressPress_ && !longPressFired_ && (now - pressedAt_ >= LONG_PRESS_MS))
    {
        longPressFired_ = true;
        pendingClicks_ = 0; // long press pre-empts any pending click/double-click
        pendingEvent_ = ButtonEvent::LongPress;
    }

    if (pendingClicks_ > 0 && !pressed_ && (now - lastReleaseAt_ > DOUBLE_CLICK_MS))
    {
        pendingEvent_ = (pendingClicks_ >= 2) ? ButtonEvent::DoubleClick : ButtonEvent::Click;
        pendingClicks_ = 0;
    }
}

int32_t JogWheel::takeRotationDelta()
{
    int32_t v = rotationAccum_;
    rotationAccum_ = 0;
    return v;
}

ButtonEvent JogWheel::takeButtonEvent()
{
    ButtonEvent e = pendingEvent_;
    pendingEvent_ = ButtonEvent::None;
    return e;
}

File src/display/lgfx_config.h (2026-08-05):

#pragma once

// LGFX panel definition for the CrowPanel 1.28" round display (GC9A01).
// Ported from Elecrow's factory example (RotaryScreen_1_28_new.ino) --
// pin values now come from pins.h instead of being repeated here.

#define LGFX_USE_V1
#include <LovyanGFX.hpp>

#include "pins.h"

class LGFX : public lgfx::LGFX_Device
{
    lgfx::Panel_GC9A01 _panel_instance;
    lgfx::Bus_SPI _bus_instance;

public:
    LGFX(void)
    {
        {
            auto cfg = _bus_instance.config();
            cfg.spi_host = SPI2_HOST;
            cfg.spi_mode = 0;
            cfg.freq_write = 80000000;
            cfg.freq_read = 20000000;
            cfg.spi_3wire = true;
            cfg.use_lock = true;
            cfg.dma_channel = SPI_DMA_CH_AUTO;
            cfg.pin_sclk = PIN_LCD_SCLK;
            cfg.pin_mosi = PIN_LCD_MOSI;
            cfg.pin_miso = PIN_LCD_MISO;
            cfg.pin_dc = PIN_LCD_DC;
            _bus_instance.config(cfg);
            _panel_instance.setBus(&_bus_instance);
        }
        {
            auto cfg = _panel_instance.config();
            cfg.pin_cs = PIN_LCD_CS;
            cfg.pin_rst = PIN_LCD_RST;
            cfg.pin_busy = -1;
            cfg.memory_width = 240;
            cfg.memory_height = 240;
            cfg.panel_width = 240;
            cfg.panel_height = 240;
            cfg.offset_x = 0;
            cfg.offset_y = 0;
            cfg.offset_rotation = 0;
            cfg.dummy_read_pixel = 8;
            cfg.dummy_read_bits = 1;
            cfg.readable = false;
            cfg.invert = true;
            cfg.rgb_order = false;
            cfg.dlen_16bit = false;
            cfg.bus_shared = false;
            _panel_instance.config(cfg);
        }
        setPanel(&_panel_instance);
    }
};

inline void backlightInit()
{
    ledcSetup(BACKLIGHT_PWM_CHANNEL, BACKLIGHT_PWM_FREQ, BACKLIGHT_PWM_RESOLUTION);
    ledcAttachPin(PIN_LCD_BACKLIGHT, BACKLIGHT_PWM_CHANNEL);
    ledcWrite(BACKLIGHT_PWM_CHANNEL, 255); // full brightness by default
}

// percent: 0-100
inline void backlightSet(uint8_t percent)
{
    if (percent > 100) percent = 100;
    ledcWrite(BACKLIGHT_PWM_CHANNEL, (percent * 255) / 100);
}

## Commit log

2026-08-05 Initial commit: terraTouch CrowPanel control panel for terraPen
    Standalone ESP32-S3 round-touchscreen pendant for a FluidNC pen plotter:
    WebSocket link to FluidNC, HTTP client for the terraPixel rail light,
    radial dial navigation (jog/files/pen/home/lights), and NVS-backed
    settings.
2026-08-13 Radial UI rework, sleep mode, and a fix for the UI stalls
    Unify every browsing screen on one shared RadialRing widget, extracted
    from the home dial: Home keeps the full circle, while Jobs and Settings
    use an open arc that leaves the bottom of the face clear of the back
    button and lets long lists scroll rather than cramming onto one circle.
    Carousel and the LVGL encoder bridge had no users left and are removed.
    Fix the stuttering that appeared whenever the plotter was connected. The
    cause was blocking network work sharing the loop that drives rendering
    and touch -- mDNS lookups (~2s), WebSocket frame reads (was 5s) and
    terraPixel HTTP calls (~1s), the last of which ran on every screen, not
    j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
    [backplate.dxf, dial case.stl, frame mount.stl]
2026-08-13 Add generated screen illustrations to the README
    Twelve SVGs, one per screen, produced by tools/gen_screens.py from the
    layout code's own values -- palette hex, ring radii, arc angles, hub and
    font sizes -- so proportions and colours track the firmware.
    They are illustrations, not screenshots: there's no way to capture the
    panel's framebuffer from a build machine, and icons are simplified
    stand-ins for LVGL's symbol font. The README says so plainly rather than
    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
2026-08-13 Drive the rail light strip directly, retiring terraPixel
    The panel mounts on the plotter beside the rail, so the separate ESP32-C3
    that used to run the strip is redundant. Its behaviour is ported into
    src/led/rail_leds.h -- the position-following comet with its raised-cosine
    taper, the per-mode status animations, film mode and party mode, all with
    the original colours and timings so the machine still reads the same from
    across the room.
    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
2026-08-13 Keep the rail lights a separate product, and unblock their client
    Reverts 1c2eb7f. Folding the rail strip into the panel meant a second
    cable out the back of the display -- power plus a data run to the rail --
    and tied the two together as one product. Two boards that each need only
    power is the better trade, so terraPixel keeps the strip and terraTouch
    talks to it. It also stays independent: terraPixel holds its own FluidNC
    connection for carriage position, so the lights work with no dial present.
    What doesn't come back is the bug. Every call in this client blocks for up
    to a second, plus an mDNS lookup when the host is unresolved, and they were
    being made from the Lights screen's widget ca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
    [fluidnc_client.cpp, main.cpp, pins.h]
2026-08-14 Add terraPen branding: About links, QR codes and an idle logo screen
    The About panel now carries the project identity -- the terraPen mark, the
    name and terrapen.xyz -- above QR codes for the site and the source repo,
    then the existing hostname/IP/uptime diagnostics. QR rather than text
    because a 240px round dial is no place to read a URL, let alone type one,
    but a phone reads one off the glass fine. LV_USE_QRCODE enables LVGL's
    bundled qrcodegen, so the codes are generated from the URLs at runtime
    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
2026-08-14 README: note USB power and battery-pack use
    It is a single-USB-C device -- power, serial and flashing on one lead, no
    separate supply -- so it runs off a battery pack, which matters for a
    plotter away from a socket or for filming without a cable in shot.
    Flags the real gotcha rather than just claiming it works: many banks cut
    out once draw drops, and screen sleep makes that likelier by switching the
    backlight off. Points at the sleep setting and the ring brightness as the
    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
2026-08-29 Add an MIT licence, matching terraForge
    The README has carried a "No licence specified yet" placeholder since the
    initial commit, which leaves the repo all-rights-reserved by default -- no
    one can legally use or fork the firmware, including anyone building their
    own panel from the STLs and the BOM.
    MIT to match its sibling terraForge, so the two halves of the toolchain
    carry the same terms. Copyright is Edward Ward rather than terraForge's
    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
2026-08-29 README: terraForge is the parent project, not a sibling
    The intro has called terraForge a sibling since the initial commit, lumping
    it in with terraPixel. terraPixel is a sibling -- a separate board this panel
    talks to -- but terraDial descends from terraForge, and takes its colour
    palette from it. The licence section, added last commit, repeated the error.
2026-08-29 Park-for-photo macro, a 100mm jog step, and scrolling job names
    Three things asked for together; the first two are small, the third isn't.
    SCROLLING JOB NAMES. The Jobs hub label was LV_LABEL_LONG_DOT at 82px, so
    it ellipsised at roughly a dozen characters. Plotter files are named by
    layer -- "drawing 1", "drawing 2", "drawing 3" -- which puts the one
    character that tells them apart in exactly the position the ellipsis eats.
    Every name in that hub is a name you are choosing between, so the end of it
    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
2026-08-29 Make the stop reachable and legible, and calm the ring during a plot
    All from watching the panel used while something was going wrong: the stop
    was hard to find, hard to be sure you'd hit, and the ring was busiest during
    the hour when nothing needs your attention.
    E-STOP FIRES ON PRESS. It was on LV_EVENT_CLICKED, which requires the touch
    to go down AND come back up inside the button. That is the right contract
    for an ordinary control -- it is what lets you slide off one you didn't mean
    to hit -- and the wrong one here: the gesture this button receives is a
    panicked jab at a 1.28" screen with the other hand already reaching for the
    machine, and a jab that lands and drags off is exactly what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
    [main.cpp]
2026-09-02 latest build and STL files
    [dial case.stl, frame mount.stl]
2026-09-09 Publish hyphenated tags as prereleases
    There was no way to cut a real, downloadable build without every panel
    being offered it on its next check. A tag containing a hyphen now
    publishes as a prerelease, which both the updater and the installer page
    skip -- they ask for releases/latest, and that endpoint ignores
    prereleases and drafts.
    It also closes a sharp edge rather than adding one. versionRank() stops
    at the first non-digit, so "0.2.0-rc1" ranks identically to "0.2.0" --
    two different builds the updater cannot distinguish. Keeping suffixed
    tags out of `latest` means it never has to.
    pages.yml moves to the same releases/latest endpoint for the same
    reason: `gh release view` picks the mo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
